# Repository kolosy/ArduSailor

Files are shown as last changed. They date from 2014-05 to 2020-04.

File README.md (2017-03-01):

ArduSailor
==========
ArduSailor is an autonomous sail boat project based on the Arduino platform. Using a modified Arduino Mega board (schematics under `layout`), ArduSailor can be programmed with a set of GPS waypoints that it can then sail to.

The platform is built around a simple, two-servo sail boat design, with a winch servo for sail plan control and a rudder servo for steering. The circuit layout included is for a modified Arduino Mega 2560, which includes:

* A 9DOF IMU (an Invensense MPU9250)
* A break-out for a weather vane (this circuit is also included)
* A microSD card
* Two servo breakouts
* Three power regulators (one to provide 6V for the servos, one to provide 3.3V for the rest and one MPPT solar charger for the LiPo)
* A GPS chip (Venus 638FPLx)
* A breakout for a UART-based camera module (currently unused)
* A battery input (currently running from a 3S LiPo battery pack)
* A breakout for the main UART port for logging (on my build I have this routed to a 433MHz radio module)
* ICSP header for programming

The included firmware operates off of a list of GPS waypoints, and is a very rudimentary implementation of a greedy algorithm for navigation. The pilot simply tries to point the boat as close to the next waypoint as it can, without falling into irons. Tacks are limited by a timer. A recent addition is stall control - if boat speed falls below a certain limit, it will fall off to beam reach (position itself with the wind coming in at a 90 degree angle) until it comes back up to speed. There is no cross-track correction

Status
======
I've built several iterations of the circuit board, and it works reliably. When at speed, the navigation works .. somewhat. My current testing is in a sub-optimal body of water (a long, narrow channel), making certain tests difficult.

Here's what I need to tackle

Short-term
----------
* Finish debugging basic piloting and navigation.
* Add cross-track correction
* Add heel compensation
* Add camera module support

Longer-term
-----------
* Improve the navigation algorithm to include no-go zones
* Add wind speed sensor (hw)

Pie-in-the-sky
--------
I'd like to replace the pilot code entirely with AI. This should be reduce-able to an optimization problem... but that's a bit beyond me right now.

Enjoy!

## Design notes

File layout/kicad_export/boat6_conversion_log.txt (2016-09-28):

#********** START OF renumber-sheet.ulp ULP Version 4.4.4 05-09-2016 :21:45:09 LOG **********#
#OldRef				SheetNumber	NewRef
CAM				1	CAM45
STATUS				1	STATUS45
S_RUD				1	S_RUD45
S_WINCH				1	S_WINCH45
WIND				1	WIND45
#********** END OF renumber-sheet.ulp ULP Version 4.4.4 05-09-2016 :21:45:09 LOG **********#

#********** START OF fix_via_hack.ulp ULP Version 4.6.0 05-09-2016 :21:45:46 LOG **********#
TRACK	WireCount=1		Net=GND				start(X=75950.000000 Y=27750.000000)	end(X=77000.000000 Y=27750.000000 )
TRACK	WireCount=2		Net=GND				start(X=77000.000000 Y=27750.000000)	end(X=77000.000000 Y=27850.000000 )
TRACK	WireCount=3		Net=GND				start(X=60000.000000 Y=12000.000000)	end(X=60000.000000 Y=11000.000000 )
TRACK	WireCount=4		Net=GND				start(X=23850.000000 Y=46100.000000)	end(X=23850.000000 Y=45300.000000 )
TRACK	WireCount=5		Net=GND				start(X=23850.000000 Y=45300.000000)	end(X=24250.000000 Y=45300.000000 )
TRACK	WireCount=6		Net=GND				start(X=24250.000000 Y=45300.000000)	end(X=24250.000000 Y=45700.000000 )
TRACK	WireCount=7		Net=GND				start(X=24250.000000 Y=45700.000000)	end(X=24100.000000 Y=45700.000000 )
TRACK	WireCount=8		Net=GND				start(X=76000.000000 Y=27750.000000)	end(X=75850.000000 Y=27750.000000 )
TRACK	WireCount=9		Net=GND				start(X=75600.000000 Y=28000.000000)	end(X=75550.000000 Y=28000.000000 )
TRACK	WireCount=10		Net=GND				start(X=75550.000000 Y=28000.000000)	end(X=75550.000000 Y=29600.000000 )
TRACK	WireCount=11		Net=GND				start(X=75550.000000 Y=29600.000000)	end(X=76450.000000 Y=29600.000000 )
TRACK	WireCount=12		Net=GND				start(X=76450.000000 Y=29600.000000)	end(X=76450.000000 Y=29500.000000 )
TRACK	WireCount=13		Net=GND				start(X=76450.000000 Y=29500.000000)	end(X=76350.000000 Y=29500.000000 )
TRACK	WireCount=14		Net=GND				start(X=76350.000000 Y=29500.000000)	end(X=76350.000000 Y=28200.000000 )
TRACK	WireCount=15		Net=GND				start(X=76350.000000 Y=28200.000000)	end(X=75900.000000 Y=28200.000000 )
TRACK	WireCount=16		Net=GND				start(X=75900.000000 Y=28200.000000)	end(X=75900.000000 Y=29100.000000 )
VIA	ViaCount=1		Net=3.3V				(X=70000.000000 Y=36000.000000)	LayerStart=1	LayerEnd=16
VIA	ViaCount=2		Net=GND				(X=17970.000000 Y=10285.000000)	LayerStart=1	LayerEnd=16
VIA	ViaCount=3		Net=GND				(X=16970.000000 Y=17317.500000)	LayerStart=1	LayerEnd=16
VIA	ViaCount=4		Net=GND				(X=22270.000000 Y=8390.000000)	LayerStart=1	LayerEnd=16
VIA	ViaCount=5		Net=GND				(X=63000.000000 Y=22000.000000)	LayerStart=1	LayerEnd=16
VIA	ViaCount=6		Net=GND				(X=78000.000000 Y=8000.000000)	LayerStart=1	LayerEnd=16
VIA	ViaCount=7		Net=GND				(X=76000.000000 Y=24000.000000)	LayerStart=1	LayerEnd=16
VIA	ViaCount=8		Net=GND				(X=76000.000000 Y=22000.000000)	LayerStart=1	LayerEnd=16
VIA	ViaCount=9		Net=GND				(X=75000.000000 Y=22000.000000)	LayerStart=1	LayerEnd=16
VIA	ViaCount=10		Net=GND				(X=75450.000000 Y=34400.000000)	LayerStart=1	LayerEnd=16
VIA	ViaCount=11		Net=GND				(X=41000.000000 Y=11000.000000)	LayerStart=1	LayerEnd=16
VIA	ViaCount=12		Net=GND				(X=53000.000000 Y=41000.000000)	LayerStart=1	LayerEnd=16
VIA	ViaCount=13		Net=GND				(X=32000.000000 Y=39000.000000)	LayerStart=1	LayerEnd=16
VIA	ViaCount=14		Net=GND				(X=4000.000000 Y=26000.000000)	LayerStart=1	LayerEnd=16
VIA	ViaCount=15		Net=GND				(X=10000.000000 Y=21000.000000)	LayerStart=1	LayerEnd=16
VIA	ViaCount=16		Net=GND				(X=4000.000000 Y=21000.000000)	LayerStart=1	LayerEnd=16
VIA	ViaCount=17		Net=GND				(X=34000.000000 Y=6000.000000)	LayerStart=1	LayerEnd=16
VIA	ViaCount=18		Net=GND				(X=40000.000000 Y=27000.000000)	LayerStart=1	LayerEnd=16
VIA	ViaCount=19		Net=GND				(X=30200.000000 Y=30150.000000)	LayerStart=1	LayerEnd=16
VIA	ViaCount=20		Net=GND				(X=10000.000000 Y=26000.000000)	LayerStart=1	LayerEnd=16
VIA	ViaCount=21		Net=GND				(X=3850.000000 Y=33350.000000)	LayerStart=1	LayerEnd=16
VIA	ViaCount=22		Net=GND				(X=14000.000000 Y=29000.000000)	LayerStart=1	LayerEnd=16
VIA	ViaCount=23		Net=GND				(X=33450.000000 Y=20700.000000)	LayerStart=1	LayerEnd=16
VIA	ViaCount=24		Net=GND				(X=65000.000000 Y=41000.000000)	LayerStart=1	LayerEnd=16
VIA	ViaCount=25		Net=GND				(X=63000.000000 Y=27000.000000)	LayerStart=1	LayerEnd=16
VIA	ViaCount=26		Net=GND				(X=57000.000000 Y=35000.000000)	LayerStart=1	LayerEnd=16
VIA	ViaCount=27		Net=GND				(X=63000.000000 Y=17000.000000)	LayerStart=1	LayerEnd=16
VIA	ViaCount=28		Net=GND				(X=76000.000000 Y=33400.000000)	LayerStart=1	LayerEnd=16
VIA	ViaCount=29		Net=GND				(X=73000.000000 Y=45000.000000)	LayerStart=1	LayerEnd=16
VIA	ViaCount=30		Net=GND				(X=63000.000000 Y=32000.000000)	LayerStart=1	LayerEnd=16
VIA	ViaCount=31		Net=GND				(X=42000.000000 Y=52000.000000)	LayerStart=1	LayerEnd=16
VIA	ViaCount=32		Net=GND				(X=29000.000000 Y=17000.000000)	LayerStart=1	LayerEnd=16
VIA	ViaCount=33		Net=GND				(X=79000.000000 Y=45000.000000)	LayerStart=1	LayerEnd=16
VIA	ViaCount=34		Net=GND				(X=41000.000000 Y=16000.000000)	LayerStart=1	LayerEnd=16
VIA	ViaCount=35		Net=GND				(X=75000.000000 Y=24000.000000)	LayerStart=1	LayerEnd=16
VIA	ViaCount=36		Net=GND				(X=81000.000000 Y=9000.000000)	LayerStart=1	LayerEnd=16
VIA	ViaCount=37		Net=GND				(X=82000.000000 Y=11000.000000)	LayerStart=1	LayerEnd=16
VIA	ViaCount=38		Net=GND				(X=76550.000000 Y=34400.000000)	LayerStart=1	LayerEnd=16
VIA	ViaCount=39		Net=GND				(X=63000.000000 Y=2000.000000)	LayerStart=1	LayerEnd=16
VIA	ViaCount=40		Net=GND				(X=58000.000000 Y=2000.000000)	LayerStart=1	LayerEnd=16
VIA	ViaCount=41		Net=GND				(X=57650.000000 Y=40550.000000)	LayerStart=1	LayerEnd=16
VIA	ViaCount=42		Net=GND				(X=53000.000000 Y=2000.000000)	LayerStart=1	LayerEnd=16
VIA	ViaCount=43		Net=GND				(X=53000.000000 Y=6000.000000)	LayerStart=1	LayerEnd=16
VIA	ViaCount=44		Net=GND				(X=35000.000000 Y=41000.000000)	LayerStart=1	LayerEnd=16
VIA	ViaCount=45		Net=GND				(X=65000.000000 Y=45000.000000)	LayerStart=1	LayerEnd=16
VIA	ViaCount=46		Net=GND				(X=73000.000000 Y=50000.000000)	LayerStart=1	LayerEnd=16
VIA	ViaCount=47		Net=GND				(X=15000.000000 Y=21000.000000)	LayerStart=1	LayerEnd=16
VIA	ViaCount=48		Net=GND				(X=25000.000000 Y=30000.000000)	LayerStart=1	LayerEnd=16
VIA	ViaCount=49		Net=GND				(X=27150.000000 Y=30000.000000)	LayerStart=1	LayerEnd=16
VIA	ViaCount=50		Net=GND				(X=24886.000000 Y=46563.000000)	LayerStart=1	LayerEnd=16
VIA	ViaCount=51		Net=GND				(X=25836.000000 Y=46763.000000)	LayerStart=1	LayerEnd=16
VIA	ViaCount=52		Net=GND				(X=43000.000000 Y=20000.000000)	LayerStart=1	LayerEnd=16
VIA	ViaCount=53		Net=GND				(X=49000.000000 Y=12000.000000)	LayerStart=1	LayerEnd=16
VIA	ViaCount=54		Net=GND				(X=79000.000000 Y=8000.000000)	LayerStart=1	LayerEnd=16
VIA	ViaCount=55		Net=GND				(X=81000.000000 Y=8000.000000)	LayerStart=1	LayerEnd=16
VIA	ViaCount=56		Net=GND				(X=19000.000000 Y=21000.000000)	LayerStart=1	LayerEnd=16
VIA	ViaCount=57		Net=GND				(X=49000.000000 Y=19900.000000)	LayerStart=1	LayerEnd=16
VIA	ViaCount=58		Net=GND				(X=10000.000000 Y=35000.000000)	LayerStart=1	LayerEnd=16
VIA	ViaCount=59		Net=GND				(X=13000.000000 Y=4000.000000)	LayerStart=1	LayerEnd=16
VIA	ViaCount=60		Net=GND				(X=29200.000000 Y=36150.000000)	LayerStart=1	LayerEnd=16
VIA	ViaCount=61		Net=GND				(X=69000.000000 Y=41000.000000)	LayerStart=1	LayerEnd=16
VIA	ViaCount=62		Net=GND				(X=43000.000000 Y=9000.000000)	LayerStart=1	LayerEnd=16
VIA	ViaCount=63		Net=GND				(X=48000.000000 Y=9000.000000)	LayerStart=1	LayerEnd=16
VIA	ViaCount=64		Net=GND				(X=52500.000000 Y=27800.000000)	LayerStart=1	LayerEnd=16
VIA	ViaCount=65		Net=GND				(X=81000.000000 Y=10000.000000)	LayerStart=1	LayerEnd=16
VIA	ViaCount=66		Net=GND				(X=45900.000000 Y=32250.000000)	LayerStart=1	LayerEnd=16
VIA	ViaCount=67		Net=GND				(X=77000.000000 Y=8000.000000)	LayerStart=1	LayerEnd=16
VIA	ViaCount=68		Net=GND				(X=76000.000000 Y=8000.000000)	LayerStart=1	LayerEnd=16
VIA	ViaCount=69		Net=GND				(X=76000.000000 Y=25000.000000)	LayerStart=1	LayerEnd=16
VIA	ViaCount=70		Net=GND				(X=40100.000000 Y=36400.000000)	LayerStart=1	LayerEnd=16
VIA	ViaCount=71		Net=GND				(X=63000.000000 Y=12000.000000)	LayerStart=1	LayerEnd=16
VIA	ViaCount=72		Net=GND				(X=63000.000000 Y=6000.000000)	LayerStart=1	LayerEnd=16
VIA	ViaCount=73		Net=GND				(X=19000.000000 Y=45000.000000)	LayerStart=1	LayerEnd=16
VIA	ViaCount=74		Net=GND				(X=19000.000000 Y=50000.000000)	LayerStart=1	LayerEnd=16
VIA	ViaCount=75		Net=GND				(X=34000.000000 Y=14000.000000)	LayerStart=1	LayerEnd=16
VIA	ViaCount=76		Net=GND				(X=34000.000000 Y=3000.000000)	LayerStart=1	LayerEnd=16
VIA	ViaCount=77		Net=GND				(X=44500.000000 Y=36400.000000)	LayerStart=1	LayerEnd=16
VIA	ViaCount=78		Net=GND				(X=43800.000000 Y=39800.000000)	LayerStart=1	LayerEnd=16
VIA	ViaCount=79		Net=GND				(X=44600.000000 Y=39800.000000)	LayerStart=1	LayerEnd=16
VIA	ViaCount=80		Net=GND				(X=29000.000000 Y=45000.000000)	LayerStart=1	LayerEnd=16
VIA	ViaCount=81		Net=GND				(X=35000.000000 Y=45000.000000)	LayerStart=1	LayerEnd=16
VIA	ViaCount=82		Net=GND				(X=76550.000000 Y=36400.000000)	LayerStart=1	LayerEnd=16
VIA	ViaCount=83		Net=GND				(X=75450.000000 Y=36400.000000)	LayerStart=1	LayerEnd=16
VIA	ViaCount=84		Net=GND				(X=47300.000000 Y=41950.000000)	LayerStart=1	LayerEnd=16
VIA	ViaCount=85		Net=GND				(X=40200.000000 Y=16000.000000)	LayerStart=1	LayerEnd=16
VIA	ViaCount=86		Net=GND				(X=41800.000000 Y=16000.000000)	LayerStart=1	LayerEnd=16
VIA	ViaCount=87		Net=GND				(X=84900.000000 Y=39800.000000)	LayerStart=1	LayerEnd=16
VIA	ViaCount=88		Net=GND				(X=85800.000000 Y=41850.000000)	LayerStart=1	LayerEnd=16
VIA	ViaCount=89		Net=GND				(X=32000.000000 Y=38000.000000)	LayerStart=1	LayerEnd=16
VIA	ViaCount=90		Net=GND				(X=29550.000000 Y=30750.000000)	LayerStart=1	LayerEnd=16
VIA	ViaCount=91		Net=GND				(X=38250.000000 Y=17550.000000)	LayerStart=1	LayerEnd=16
VIA	ViaCount=92		Net=GND				(X=37400.000000 Y=17550.000000)	LayerStart=1	LayerEnd=16
VIA	ViaCount=93		Net=GND				(X=54250.000000 Y=28950.000000)	LayerStart=1	LayerEnd=16
VIA	ViaCount=94		Net=GND				(X=54250.000000 Y=29750.000000)	LayerStart=1	LayerEnd=16
VIA	ViaCount=95		Net=GND				(X=48350.000000 Y=29800.000000)	LayerStart=1	LayerEnd=16
VIA	ViaCount=96		Net=GND				(X=45600.000000 Y=28250.000000)	LayerStart=1	LayerEnd=16
VIA	ViaCount=97		Net=RFGND				(X=4000.000000 Y=3300.000000)	LayerStart=1	LayerEnd=16
VIA	ViaCount=98		Net=RFGND				(X=1460.000000 Y=18540.000000)	LayerStart=1	LayerEnd=16
VIA	ViaCount=99		Net=RFGND				(X=1460.000000 Y=3300.000000)	LayerStart=1	LayerEnd=16
VIA	ViaCount=100		Net=RFGND				(X=1460.000000 Y=12190.000000)	LayerStart=1	LayerEnd=16
VIA	ViaCount=101		Net=RFGND				(X=4000.000000 Y=12190.000000)	LayerStart=1	LayerEnd=16
PADFILL	PadCount=1		Net=3.3V				(X=54200.000000 Y=10280.000000)	LayerStart=1	LayerEnd=1
PADFILL	PadCount=2		Net=GND				(X=54200.000000 Y=11980.000000)	LayerStart=1	LayerEnd=1
PADFILL	PadCount=4		Net=GND				(X=58100.000000 Y=15070.000000)	LayerStart=1	LayerEnd=1
PADFILL	PadCount=5		Net=3.3V				(X=60780.000000 Y=8470.000000)	LayerStart=1	LayerEnd=1
PADFILL	PadCount=6		Net=GND				(X=62480.000000 Y=8470.000000)	LayerStart=1	LayerEnd=1
PADFILL	PadCount=8		Net=GND				(X=57910.000000 Y=4570.000000)	LayerStart=1	LayerEnd=1
PADFILL	PadCount=10		Net=GND				(X=21930.000000 Y=11770.000000)	LayerStart=1	LayerEnd=1
PADFILL	PadCount=12		Net=GND				(X=19875.000000 Y=12320.000000)	LayerStart=1	LayerEnd=1
PADFILL	PadCount=14		Net=GND				(X=20492.500000 Y=7007.500000)	LayerStart=1	LayerEnd=1
PADFILL	PadCount=16		Net=RFGND				(X=7479.000000 Y=4735.000000)	LayerStart=1	LayerEnd=1
PADFILL	PadCount=20		Net=GND				(X=19025.000000 Y=16476.100000)	LayerStart=1	LayerEnd=1
PADFILL	PadCount=22		Net=GND				(X=36900.000000 Y=41289.000000)	LayerStart=1	LayerEnd=1
PADFILL	PadCount=23		Net=3.3V				(X=51511.000000 Y=29350.000000)	LayerStart=1	LayerEnd=1
PADFILL	PadCount=24		Net=GND				(X=53289.000000 Y=29350.000000)	LayerStart=1	LayerEnd=1
PADFILL	PadCount=27		Net=3.3V				(X=32539.000000 Y=31850.000000)	LayerStart=1	LayerEnd=1
PADFILL	PadCount=28		Net=GND				(X=30761.000000 Y=31850.000000)	LayerStart=1	LayerEnd=1
PADFILL	PadCount=29		Net=3.3V				(X=35089.000000 Y=38250.000000)	LayerStart=1	LayerEnd=1
PADFILL	PadCount=30		Net=GND				(X=33311.000000 Y=38250.000000)	LayerStart=1	LayerEnd=1
PADFILL	PadCount=32		Net=GND				(X=37750.000000 Y=18711.000000)	LayerStart=1	LayerEnd=1
PADFILL	PadCount=33		Net=V_BATT				(X=85400.000000 Y=8850.000000)	LayerStart=1	LayerEnd=1
PADFILL	PadCount=34		Net=GND				(X=82600.000000 Y=8850.000000)	LayerStart=1	LayerEnd=1
PADFILL	PadCount=35		Net=5V				(X=83100.000000 Y=21050.000000)	LayerStart=1	LayerEnd=1
PADFILL	PadCount=39		Net=5V				(X=76000.000000 Y=3600.000000)	LayerStart=1	LayerEnd=1
PADFILL	PadCount=40		Net=GND				(X=76000.000000 Y=6400.000000)	LayerStart=1	LayerEnd=1
PADFILL	PadCount=41		Net=V_BATT				(X=77900.000000 Y=26700.000000)	LayerStart=1	LayerEnd=1
PADFILL	PadCount=42		Net=GND				(X=76100.000000 Y=26700.000000)	LayerStart=1	LayerEnd=1
PADFILL	PadCount=43		Net=3.3V				(X=74100.000000 Y=31450.000000)	LayerStart=1	LayerEnd=1
PADFILL	PadCount=44		Net=GND				(X=75900.000000 Y=31450.000000)	LayerStart=1	LayerEnd=1
PADFILL	PadCount=45		Net=GND				(X=26350.000000 Y=27900.000000)	LayerStart=1	LayerEnd=1
PADFILL	PadCount=46		Net=3.3V				(X=26350.000000 Y=38100.000000)	LayerStart=1	LayerEnd=1
PADFILL	PadCount=49		Net=3.3V				(X=23840.000000 Y=41010.000000)	LayerStart=1	LayerEnd=1
PADFILL	PadCount=50		Net=GND				(X=25540.000000 Y=41010.000000)	LayerStart=1	LayerEnd=1
PADFILL	PadCount=54		Net=GND				(X=25320.000000 Y=48191.000000)	LayerStart=1	LayerEnd=1
PADFILL	PadCount=55		Net=3.3V				(X=46100.000000 Y=39550.000000)	LayerStart=1	LayerEnd=1
PADFILL	PadCount=56		Net=GND				(X=46100.000000 Y=41250.000000)	LayerStart=1	LayerEnd=1
PADFILL	PadCount=59		Net=GND				(X=26700.000000 Y=4200.000000)	LayerStart=1	LayerEnd=1
PADFILL	PadCount=61		Net=5V				(X=78000.000000 Y=3600.000000)	LayerStart=1	LayerEnd=1
PADFILL	PadCount=62		Net=GND				(X=78000.000000 Y=6400.000000)	LayerStart=1	LayerEnd=1
PADFILL	PadCount=63		Net=V_BATT				(X=84900.000000 Y=10600.000000)	LayerStart=1	LayerEnd=1
PADFILL	PadCount=64		Net=GND				(X=83100.000000 Y=10600.000000)	LayerStart=1	LayerEnd=1
PADFILL	PadCount=65		Net=3.3V				(X=78500.000000 Y=33400.000000)	LayerStart=1	LayerEnd=1
PADFILL	PadCount=74		Net=5V				(X=50300.000000 Y=47000.000000)	LayerStart=1	LayerEnd=1
PADFILL	PadCount=76		Net=5V				(X=61950.000000 Y=47000.000000)	LayerStart=1	LayerEnd=1
PADFILL	PadCount=80		Net=3.3V				(X=46300.000000 Y=14000.000000)	LayerStart=1	LayerEnd=1
PADFILL	PadCount=90		Net=3.3V				(X=34000.000000 Y=31500.000000)	LayerStart=1	LayerEnd=1
PADFILL	PadCount=91		Net=GND				(X=34000.000000 Y=31000.000000)	LayerStart=1	LayerEnd=1
PADFILL	PadCount=111		Net=3.3V				(X=38500.000000 Y=22000.000000)	LayerStart=1	LayerEnd=1
PADFILL	PadCount=112		Net=GND				(X=39000.000000 Y=22000.000000)	LayerStart=1	LayerEnd=1
PADFILL	PadCount=141		Net=3.3V				(X=50000.000000 Y=29000.000000)	LayerStart=1	LayerEnd=1
PADFILL	PadCount=142		Net=GND				(X=50000.000000 Y=29500.000000)	LayerStart=1	LayerEnd=1
PADFILL	PadCount=160		Net=3.3V				(X=46000.000000 Y=38000.000000)	LayerStart=1	LayerEnd=1
PADFILL	PadCount=161		Net=GND				(X=45500.000000 Y=38000.000000)	LayerStart=1	LayerEnd=1
PADFILL	PadCount=179		Net=GND				(X=36500.000000 Y=38000.000000)	LayerStart=1	LayerEnd=1
PADFILL	PadCount=180		Net=3.3V				(X=36000.000000 Y=38000.000000)	LayerStart=1	LayerEnd=1
PADFILL	PadCount=196		Net=RFGND				(X=2323.600000 Y=10259.600000)	LayerStart=1	LayerEnd=1
PADFILL	PadCount=197		Net=RFGND				(X=2323.600000 Y=5179.600000)	LayerStart=1	LayerEnd=1
PADFILL	PadCount=198		Net=RFGND				(X=2323.600000 Y=10259.600000)	LayerStart=16	LayerEnd=16
PADFILL	PadCount=199		Net=RFGND				(X=2323.600000 Y=5179.600000)	LayerStart=16	LayerEnd=16
PADFILL	PadCount=204		Net=3.3V				(X=71950.000000 Y=29370.000000)	LayerStart=1	LayerEnd=1
PADFILL	PadCount=206		Net=5V				(X=80000.000000 Y=4150.000000)	LayerStart=1	LayerEnd=1
PADFILL	PadCount=208		Net=GND				(X=85050.000000 Y=41100.000000)	LayerStart=1	LayerEnd=1
PADFILL	PadCount=211		Net=3.3V				(X=6050.000000 Y=46000.000000)	LayerStart=1	LayerEnd=1
PADFILL	PadCount=214		Net=3.3V				(X=33000.000000 Y=11950.000000)	LayerStart=1	LayerEnd=1
PADFILL	PadCount=217		Net=3.3V				(X=17250.000000 Y=39100.000000)	LayerStart=1	LayerEnd=1
PADFILL	PadCount=220		Net=GND				(X=68100.000000 Y=48950.000000)	LayerStart=1	LayerEnd=1
PADFILL	PadCount=223		Net=GND				(X=57100.000000 Y=48950.000000)	LayerStart=1	LayerEnd=1
PADFILL	PadCount=226		Net=GND				(X=82950.000000 Y=40900.000000)	LayerStart=1	LayerEnd=1
PADFILL	PadCount=229		Net=V_BATT				(X=82950.000000 Y=45050.000000)	LayerStart=1	LayerEnd=1
PADFILL	PadCount=231		Net=V_BATT				(X=80000.000000 Y=26150.000000)	LayerStart=1	LayerEnd=1
PADFILL	PadCount=233		Net=3.3V				(X=6150.000000 Y=48000.000000)	LayerStart=1	LayerEnd=1
PADFILL	PadCount=237		Net=GND				(X=20725.000000 Y=15215.000000)	LayerStart=1	LayerEnd=1
PADFILL	PadCount=243		Net=GND				(X=8762.500000 Y=7720.000000)	LayerStart=16	LayerEnd=16
PADFILL	PadCount=244		Net=RFGND				(X=7492.500000 Y=7720.000000)	LayerStart=16	LayerEnd=16
PADFILL	PadCount=251		Net=GND				(X=85150.000000 Y=48300.000000)	LayerStart=1	LayerEnd=1
PADFILL	PadCount=258		Net=5V				(X=83150.000000 Y=19500.000000)	LayerStart=1	LayerEnd=1
PADFILL	PadCount=259		Net=GND				(X=83150.000000 Y=18000.000000)	LayerStart=1	LayerEnd=1
PADFILL	PadCount=262		Net=3.3V				(X=78650.000000 Y=31900.000000)	LayerStart=1	LayerEnd=1
PADFILL	PadCount=263		Net=GND				(X=80700.000000 Y=31900.000000)	LayerStart=1	LayerEnd=1
PADFILL	PadCount=265		Net=3.3V				(X=71150.000000 Y=24000.000000)	LayerStart=1	LayerEnd=1
PADFILL	PadCount=267		Net=V_BATT				(X=86850.000000 Y=45000.000000)	LayerStart=1	LayerEnd=1
PADFILL	PadCount=269		Net=3.3V				(X=8900.000000 Y=41450.000000)	LayerStart=1	LayerEnd=1
PADFILL	PadCount=271		Net=3.3V				(X=35000.000000 Y=11850.000000)	LayerStart=1	LayerEnd=1
PADFILL	PadCount=280		Net=GND				(X=53050.000000 Y=21200.000000)	LayerStart=1	LayerEnd=1
PADFILL	PadCount=283		Net=GND				(X=82850.000000 Y=39000.000000)	LayerStart=1	LayerEnd=1
PADFILL	PadCount=290		Net=3.3V				(X=43325.000000 Y=17400.000000)	LayerStart=1	LayerEnd=1
PADFILL	PadCount=291		Net=3.3V				(X=43325.000000 Y=16600.000000)	LayerStart=1	LayerEnd=1
PADFILL	PadCount=292		Net=3.3V				(X=43325.000000 Y=15800.000000)	LayerStart=1	LayerEnd=1
PADFILL	PadCount=301		Net=GND				(X=77060.000000 Y=28250.000000)	LayerStart=1	LayerEnd=1
PADFILL	PadCount=302		Net=V_BATT				(X=77060.000000 Y=28750.000000)	LayerStart=1	LayerEnd=1
PADFILL	PadCount=306		Net=3.3V				(X=74950.000000 Y=29250.000000)	LayerStart=1	LayerEnd=1
PADFILL	PadCount=309		Net=GND				(X=76000.000000 Y=29000.000000)	LayerStart=1	LayerEnd=1
PADFILL	PadCount=312		Net=GND				(X=83050.000000 Y=12850.000000)	LayerStart=1	LayerEnd=1
PADFILL	PadCount=314		Net=V_BATT				(X=84950.000000 Y=12850.000000)	LayerStart=1	LayerEnd=1
PADFILL	PadCount=318		Net=GND				(X=55510.000000 Y=11270.000000)	LayerStart=1	LayerEnd=1
PADFILL	PadCount=320		Net=3.3V				(X=55510.000000 Y=10270.000000)	LayerStart=1	LayerEnd=1
PADFILL	PadCount=325		Net=3.3V				(X=56760.000000 Y=8020.000000)	LayerStart=1	LayerEnd=1
PADFILL	PadCount=326		Net=GND				(X=57260.000000 Y=8020.000000)	LayerStart=1	LayerEnd=1
PADFILL	PadCount=328		Net=GND				(X=58260.000000 Y=8020.000000)	LayerStart=1	LayerEnd=1
PADFILL	PadCount=330		Net=3.3V				(X=59510.000000 Y=8770.000000)	LayerStart=1	LayerEnd=1
PADFILL	PadCount=332		Net=GND				(X=59510.000000 Y=9770.000000)	LayerStart=1	LayerEnd=1
PADFILL	PadCount=334		Net=GND				(X=59510.000000 Y=10770.000000)	LayerStart=1	LayerEnd=1
PADFILL	PadCount=335		Net=GND				(X=59510.000000 Y=11270.000000)	LayerStart=1	LayerEnd=1
PADFILL	PadCount=349		Net=GND				(X=16520.000000 Y=12520.000000)	LayerStart=1	LayerEnd=1
PADFILL	PadCount=351		Net=GND				(X=16520.000000 Y=14120.000000)	LayerStart=1	LayerEnd=1
PADFILL	PadCount=352		Net=GND				(X=16520.000000 Y=14920.000000)	LayerStart=1	LayerEnd=1
PADFILL	PadCount=356		Net=GND				(X=13220.000000 Y=15820.000000)	LayerStart=1	LayerEnd=1
PADFILL	PadCount=360		Net=GND				(X=10020.000000 Y=15820.000000)	LayerStart=1	LayerEnd=1
PADFILL	PadCount=362		Net=RFGND				(X=8420.000000 Y=15820.000000)	LayerStart=1	LayerEnd=1
PADFILL	PadCount=363		Net=RFGND				(X=7620.000000 Y=15820.000000)	LayerStart=1	LayerEnd=1
PADFILL	PadCount=365		Net=RFGND				(X=6720.000000 Y=14120.000000)	LayerStart=1	LayerEnd=1
PADFILL	PadCount=366		Net=RFGND				(X=6720.000000 Y=13320.000000)	LayerStart=1	LayerEnd=1
PADFILL	PadCount=368		Net=RFGND				(X=6720.000000 Y=11720.000000)	LayerStart=1	LayerEnd=1
PADFILL	PadCount=369		Net=RFGND				(X=6720.000000 Y=10920.000000)	LayerStart=1	LayerEnd=1
PADFILL	PadCount=370		Net=RFGND				(X=6720.000000 Y=10120.000000)	LayerStart=1	LayerEnd=1
PADFILL	PadCount=372		Net=RFGND				(X=6720.000000 Y=8520.000000)	LayerStart=1	LayerEnd=1
PADFILL	PadCount=374		Net=RFGND				(X=6720.000000 Y=6920.000000)	LayerStart=1	LayerEnd=1
PADFILL	PadCount=390		Net=GND				(X=14620.000000 Y=13920.000000)	LayerStart=1	LayerEnd=1
PADFILL	PadCount=401		Net=GND				(X=10120.000000 Y=7920.000000)	LayerStart=1	LayerEnd=1
PADFILL	PadCount=402		Net=RFGND				(X=10120.000000 Y=9420.000000)	LayerStart=1	LayerEnd=1
PADFILL	PadCount=403		Net=RFGND				(X=10120.000000 Y=10920.000000)	LayerStart=1	LayerEnd=1
PADFILL	PadCount=405		Net=GND				(X=10120.000000 Y=13920.000000)	LayerStart=1	LayerEnd=1
PADFILL	PadCount=406		Net=RFGND				(X=8620.000000 Y=7920.000000)	LayerStart=1	LayerEnd=1
PADFILL	PadCount=410		Net=RFGND				(X=8620.000000 Y=13920.000000)	LayerStart=1	LayerEnd=1
PADFILL	PadCount=414		Net=3.3V				(X=5230.000000 Y=31870.000000)	LayerStart=1	LayerEnd=1
PADFILL	PadCount=416		Net=GND				(X=5230.000000 Y=34070.000000)	LayerStart=1	LayerEnd=1
PADFILL	PadCount=419		Net=GND				(X=15730.000000 Y=35460.000000)	LayerStart=1	LayerEnd=1
PADFILL	PadCount=420		Net=GND				(X=15730.000000 Y=29760.000000)	LayerStart=1	LayerEnd=1
PADFILL	PadCount=421		Net=GND				(X=1580.000000 Y=23910.000000)	LayerStart=1	LayerEnd=1
PADFILL	PadCount=422		Net=GND				(X=2580.000000 Y=37060.000000)	LayerStart=1	LayerEnd=1
PADFILL	PadCount=424		Net=3.3V				(X=22750.000000 Y=42630.000000)	LayerStart=1	LayerEnd=1
PADFILL	PadCount=426		Net=3.3V				(X=23750.000000 Y=42630.000000)	LayerStart=1	LayerEnd=1
PADFILL	PadCount=431		Net=GND				(X=23750.000000 Y=45370.000000)	LayerStart=1	LayerEnd=1
PADFILL	PadCount=433		Net=GND				(X=22750.000000 Y=45370.000000)	LayerStart=1	LayerEnd=1
PADFILL	PadCount=435		Net=3.3V				(X=21630.000000 Y=44750.000000)	LayerStart=1	LayerEnd=1
PADFILL	PadCount=444		Net=GND				(X=40800.000000 Y=17700.000000)	LayerStart=1	LayerEnd=1
#********** END OF fix_via_hack.ulp ULP Version 4.6.0 05-09-2016 :21:45:46 LOG **********#

#********** START OF eagle6xx-sch-to-kicad-sch.ulp 1.9 05-09-2016 :21:46:51 LOG **********#
Package Name Conflict: Package=C0402 from Internal SCH lib=SmartPrj  With Package=C0402 from LIB=SparkFun
Package Name Conflict: Package=R2010 from Internal SCH lib=SmartPrj  With Package=R2010 from LIB=SparkFun
Package Name Conflict: Package=R2010 from Internal SCH lib=SmartPrj  With Package=R2010 from LIB=SparkFun-Passives
Package Name Conflict: Package=R2010 from Internal SCH lib=SmartPrj  With Package=R2010 from LIB=SparkFun-Resistors
Package Name Conflict: Package=R2512 from Internal SCH lib=SmartPrj  With Package=R2512 from LIB=SparkFun
Package Name Conflict: Package=R2512 from Internal SCH lib=SmartPrj  With Package=R2512 from LIB=SparkFun-Passives
Package Name Conflict: Package=R2512 from Internal SCH lib=SmartPrj  With Package=R2512 from LIB=SparkFun-Resistors
Device Name Conflict: Device=CAP0402-CAP from Internal SCH lib=SparkFun  With Device=CAP0402-CAP from LIB=SparkFun-Capacitors
Device Name Conflict: Device=CAP0402-CAP from Internal SCH lib=SparkFun  With Device=CAP0402-CAP from LIB=SparkFun-Passives
Device Name Conflict: Device=CAP0603-CAP from Internal SCH lib=SparkFun  With Device=CAP0603-CAP from LIB=SparkFun-Capacitors
Device Name Conflict: Device=CAP0603-CAP from Internal SCH lib=SparkFun  With Device=CAP0603-CAP from LIB=SparkFun-Passives
Device Name Conflict: Device=CAP0805 from Internal SCH lib=SparkFun  With Device=CAP0805 from LIB=SparkFun-Capacitors
Device Name Conflict: Device=CAP0805 from Internal SCH lib=SparkFun  With Device=CAP0805 from LIB=SparkFun-Passives
Device Name Conflict: Device=CAP1206 from Internal SCH lib=SparkFun  With Device=CAP1206 from LIB=SparkFun-Capacitors
Device Name Conflict: Device=CAP1206 from Internal SCH lib=SparkFun  With Device=CAP1206 from LIB=SparkFun-Passives
Device Name Conflict: Device=CAP1210 from Internal SCH lib=SparkFun  With Device=CAP1210 from LIB=SparkFun-Capacitors
Device Name Conflict: Device=CAP1210 from Internal SCH lib=SparkFun  With Device=CAP1210 from LIB=SparkFun-Passives
Device Name Conflict: Device=CAPASMD from Internal SCH lib=SparkFun  With Device=CAPASMD from LIB=SparkFun-Capacitors
Device Name Conflict: Device=CAPASMD from Internal SCH lib=SparkFun  With Device=CAPASMD from LIB=SparkFun-Passives
Device Name Conflict: Device=CAPPTH from Internal SCH lib=SparkFun  With Device=CAPPTH from LIB=SparkFun-Capacitors
Device Name Conflict: Device=CAPPTH from Internal SCH lib=SparkFun  With Device=CAPPTH from LIB=SparkFun-Passives
Device Name Conflict: Device=CAPPTH1 from Internal SCH lib=SparkFun  With Device=CAPPTH1 from LIB=SparkFun-Capacitors
Device Name Conflict: Device=CAPPTH1 from Internal SCH lib=SparkFun  With Device=CAPPTH1 from LIB=SparkFun-Passives
Device Name Conflict: Device=CAPPTH2 from Internal SCH lib=SparkFun  With Device=CAPPTH2 from LIB=SparkFun-Capacitors
Device Name Conflict: Device=CAPPTH2 from Internal SCH lib=SparkFun  With Device=CAPPTH2 from LIB=SparkFun-Passives
Device Name Conflict: Device=CAPPTH3 from Internal SCH lib=SparkFun  With Device=CAPPTH3 from LIB=SparkFun-Capacitors
Device Name Conflict: Device=CAPPTH3 from Internal SCH lib=SparkFun  With Device=CAPPTH3 from LIB=SparkFun-Passives
Device Name Conflict: Device=CAPSMD from Internal SCH lib=SparkFun  With Device=CAPSMD from LIB=SparkFun-Capacitors
Device Name Conflict: Device=CAPSMD from Internal SCH lib=SparkFun  With Device=CAPSMD from LIB=SparkFun-Passives
Device Name Conflict: Device=CAP_ from Internal SCH lib=SparkFun  With Device=CAP_ from LIB=SparkFun-Capacitors
Device Name Conflict: Device=CAP_ from Internal SCH lib=SparkFun  With Device=CAP_ from LIB=SparkFun-Passives
Device Name Conflict: Device=CAP_POL1206 from Internal SCH lib=SparkFun  With Device=CAP_POL1206 from LIB=kolosy
Device Name Conflict: Device=CAP_POL1206-KIT from Internal SCH lib=SparkFun  With Device=CAP_POL1206-KIT from LIB=kolosy
Device Name Conflict: Device=CAP_POL3528 from Internal SCH lib=SparkFun  With Device=CAP_POL3528 from LIB=kolosy
Device Name Conflict: Device=CAP_POL3528-KIT from Internal SCH lib=SparkFun  With Device=CAP_POL3528-KIT from LIB=kolosy
Device Name Conflict: Device=CAP_POL6032 from Internal SCH lib=SparkFun  With Device=CAP_POL6032 from LIB=kolosy
Device Name Conflict: Device=CAP_POL7343 from Internal SCH lib=SparkFun  With Device=CAP_POL7343 from LIB=kolosy
Device Name Conflict: Device=CAP_POLC from Internal SCH lib=SparkFun  With Device=CAP_POLC from LIB=kolosy
Device Name Conflict: Device=CAP_POLD from Internal SCH lib=SparkFun  With Device=CAP_POLD from LIB=kolosy
Device Name Conflict: Device=CAP_POLE from Internal SCH lib=SparkFun  With Device=CAP_POLE from LIB=kolosy
Device Name Conflict: Device=CAP_POLEN_J2 from Internal SCH lib=SparkFun  With Device=CAP_POLEN_J2 from LIB=kolosy
Device Name Conflict: Device=CAP_POLF80 from Internal SCH lib=SparkFun  With Device=CAP_POLF80 from LIB=kolosy
Device Name Conflict: Device=CAP_POLG from Internal SCH lib=SparkFun  With Device=CAP_POLG from LIB=kolosy
Device Name Conflict: Device=CAP_POLH13 from Internal SCH lib=SparkFun  With Device=CAP_POLH13 from LIB=kolosy
Device Name Conflict: Device=CAP_POLPTH1 from Internal SCH lib=SparkFun  With Device=CAP_POLPTH1 from LIB=kolosy
Device Name Conflict: Device=CAP_POLPTH2 from Internal SCH lib=SparkFun  With Device=CAP_POLPTH2 from LIB=kolosy
Device Name Conflict: Device=CAP_POLPTH3 from Internal SCH lib=SparkFun  With Device=CAP_POLPTH3 from LIB=kolosy
Device Name Conflict: Device=CAP_POLPTH4 from Internal SCH lib=SparkFun  With Device=CAP_POLPTH4 from LIB=kolosy
Device Name Conflict: Device=CAP_POLSMD from Internal SCH lib=SparkFun  With Device=CAP_POLSMD from LIB=kolosy
Device Name Conflict: Device=GND from Internal SCH lib=SparkFun  With Device=GND from LIB=SparkFun-Aesthetics
Device Name Conflict: Device=GND from Internal SCH lib=SparkFun  With Device=GND from LIB=supply1
Device Name Conflict: Device=RESISTOR0402-RES from Internal SCH lib=SparkFun  With Device=RESISTOR0402-RES from LIB=SparkFun-Passives
Device Name Conflict: Device=RESISTOR0603-RES from Internal SCH lib=SparkFun  With Device=RESISTOR0603-RES from LIB=SparkFun-Passives
Device Name Conflict: Device=RESISTOR0603-RES from Internal SCH lib=SparkFun  With Device=RESISTOR0603-RES from LIB=SparkFun-Resistors
Device Name Conflict: Device=RESISTOR0805-RES from Internal SCH lib=SparkFun  With Device=RESISTOR0805-RES from LIB=SparkFun-Passives
Device Name Conflict: Device=RESISTOR0805-RES from Internal SCH lib=SparkFun  With Device=RESISTOR0805-RES from LIB=SparkFun-Resistors
Device Name Conflict: Device=RESISTOR1206 from Internal SCH lib=SparkFun  With Device=RESISTOR1206 from LIB=SparkFun-Passives
Device Name Conflict: Device=RESISTOR1206 from Internal SCH lib=SparkFun  With Device=RESISTOR1206 from LIB=SparkFun-Resistors
Device Name Conflict: Device=RESISTOR2010 from Internal SCH lib=SparkFun  With Device=RESISTOR2010 from LIB=SparkFun-Passives
Device Name Conflict: Device=RESISTOR2010 from Internal SCH lib=SparkFun  With Device=RESISTOR2010 from LIB=SparkFun-Resistors
Device Name Conflict: Device=RESISTOR2512 from Internal SCH lib=SparkFun  With Device=RESISTOR2512 from LIB=SparkFun-Passives
Device Name Conflict: Device=RESISTOR2512 from Internal SCH lib=SparkFun  With Device=RESISTOR2512 from LIB=SparkFun-Resistors
Device Name Conflict: Device=RESISTORAXIAL-0.3 from Internal SCH lib=SparkFun  With Device=RESISTORAXIAL-0.3 from LIB=SparkFun-Passives
Device Name Conflict: Device=RESISTORAXIAL-0.3 from Internal SCH lib=SparkFun  With Device=RESISTORAXIAL-0.3 from LIB=SparkFun-Resistors
Device Name Conflict: Device=RESISTORPTH-1/2W from Internal SCH lib=SparkFun  With Device=RESISTORPTH-1/2W from LIB=SparkFun-Passives
Device Name Conflict: Device=RESISTORPTH-1/2W from Internal SCH lib=SparkFun  With Device=RESISTORPTH-1/2W from LIB=SparkFun-Resistors
Device Name Conflict: Device=RESISTORPTH-1/4W from Internal SCH lib=SparkFun  With Device=RESISTORPTH-1/4W from LIB=SparkFun-Passives
Device Name Conflict: Device=RESISTORPTH-1/4W from Internal SCH lib=SparkFun  With Device=RESISTORPTH-1/4W from LIB=SparkFun-Resistors
Device Name Conflict: Device=RESISTORPTH-1/6W from Internal SCH lib=SparkFun  With Device=RESISTORPTH-1/6W from LIB=SparkFun-Passives
Device Name Conflict: Device=RESISTORPTH-1/6W from Internal SCH lib=SparkFun  With Device=RESISTORPTH-1/6W from LIB=SparkFun-Resistors
Device Name Conflict: Device=RESISTORPTH-1W from Internal SCH lib=SparkFun  With Device=RESISTORPTH-1W from LIB=SparkFun-Passives
Device Name Conflict: Device=RESISTORPTH-1W from Internal SCH lib=SparkFun  With Device=RESISTORPTH-1W from LIB=SparkFun-Resistors
Device Name Conflict: Device=RESISTORPTH-2W from Internal SCH lib=SparkFun  With Device=RESISTORPTH-2W from LIB=SparkFun-Passives
Device Name Conflict: Device=RESISTORPTH-2W from Internal SCH lib=SparkFun  With Device=RESISTORPTH-2W from LIB=SparkFun-Resistors
Symbol Name Conflict: Symbol=CAP from Internal SCH lib=SparkFun  With Symbol=CAP from LIB=SparkFun-Capacitors
Symbol Name Conflict: Symbol=CAP from Internal SCH lib=SparkFun  With Symbol=CAP from LIB=SparkFun-Passives
Symbol Name Conflict: Symbol=CAP_POL from Internal SCH lib=SparkFun  With Symbol=CAP_POL from LIB=kolosy
Symbol Name Conflict: Symbol=GND from Internal SCH lib=SparkFun  With Symbol=GND from LIB=supply1
Symbol Name Conflict: Symbol=RESISTOR from Internal SCH lib=SparkFun  With Symbol=RESISTOR from LIB=SparkFun-Passives
Symbol Name Conflict: Symbol=RESISTOR from Internal SCH lib=SparkFun  With Symbol=RESISTOR from LIB=SparkFun-Resistors
Package Name Conflict: Package=1/6W-RES from Internal SCH lib=SparkFun  With Package=1/6W-RES from LIB=SparkFun-Passives
Package Name Conflict: Package=1/6W-RES from Internal SCH lib=SparkFun  With Package=1/6W-RES from LIB=SparkFun-Resistors
Package Name Conflict: Package=0402-CAP from Internal SCH lib=SparkFun  With Package=0402-CAP from LIB=SparkFun-Capacitors
Package Name Conflict: Package=0402-CAP from Internal SCH lib=SparkFun  With Package=0402-CAP from LIB=SparkFun-Passives
Package Name Conflict: Package=0402-RES from Internal SCH lib=SparkFun  With Package=0402-RES from LIB=SparkFun-Passives
Package Name Conflict: Package=0603-CAP from Internal SCH lib=SparkFun  With Package=0603-CAP from LIB=SparkFun-Capacitors
Package Name Conflict: Package=0603-CAP from Internal SCH lib=SparkFun  With Package=0603-CAP from LIB=SparkFun-Passives
Package Name Conflict: Package=0603-RES from Internal SCH lib=SparkFun  With Package=0603-RES from LIB=SparkFun-Passives
Package Name Conflict: Package=0603-RES from Internal SCH lib=SparkFun  With Package=0603-RES from LIB=SparkFun-Resistors
Package Name Conflict: Package=0805 from Internal SCH lib=SparkFun  With Package=0805 from LIB=SparkFun-Capacitors
Package Name Conflict: Package=0805 from Internal SCH lib=SparkFun  With Package=0805 from LIB=SparkFun-Passives
Package Name Conflict: Package=0805 from Internal SCH lib=SparkFun  With Package=0805 from LIB=SparkFun-Resistors
Package Name Conflict: Package=1206 from Internal SCH lib=SparkFun  With Package=1206 from LIB=SparkFun-Capacitors
Package Name Conflict: Package=1206 from Internal SCH lib=SparkFun  With Package=1206 from LIB=SparkFun-Passives
Package Name Conflict: Package=1206 from Internal SCH lib=SparkFun  With Package=1206 from LIB=SparkFun-Resistors
Package Name Conflict: Package=1210 from Internal SCH lib=SparkFun  With Package=1210 from LIB=SparkFun-Capacitors
Package Name Conflict: Package=1210 from Internal SCH lib=SparkFun  With Package=1210 from LIB=SparkFun-Passives
Package Name Conflict: Package=AXIAL-0.3 from Internal SCH lib=SparkFun  With Package=AXIAL-0.3 from LIB=SparkFun-Passives
Package Name Conflict: Package=AXIAL-0.3 from Internal SCH lib=SparkFun  With Package=AXIAL-0.3 from LIB=SparkFun-Resistors
Package Name Conflict: Package=AXIAL-0.4 from Internal SCH lib=SparkFun  With Package=AXIAL-0.4 from LIB=SparkFun-Passives
Package Name Conflict: Package=AXIAL-0.4 from Internal SCH lib=SparkFun  With Package=AXIAL-0.4 from LIB=SparkFun-Resistors
Package Name Conflict: Package=AXIAL-0.5 from Internal SCH lib=SparkFun  With Package=AXIAL-0.5 from LIB=SparkFun-Passives
Package Name Conflict: Package=AXIAL-0.5 from Internal SCH lib=SparkFun  With Package=AXIAL-0.5 from LIB=SparkFun-Resistors
Package Name Conflict: Package=AXIAL-0.6 from Internal SCH lib=SparkFun  With Package=AXIAL-0.6 from LIB=SparkFun-Passives
Package Name Conflict: Package=AXIAL-0.6 from Internal SCH lib=SparkFun  With Package=AXIAL-0.6 from LIB=SparkFun-Resistors
Package Name Conflict: Package=AXIAL-0.8 from Internal SCH lib=SparkFun  With Package=AXIAL-0.8 from LIB=SparkFun-Passives
Package Name Conflict: Package=AXIAL-0.8 from Internal SCH lib=SparkFun  With Package=AXIAL-0.8 from LIB=SparkFun-Resistors
Package Name Conflict: Package=AXIAL-5MM from Internal SCH lib=SparkFun  With Package=AXIAL-5MM from LIB=SparkFun-Capacitors
Package Name Conflict: Package=AXIAL-5MM from Internal SCH lib=SparkFun  With Package=AXIAL-5MM from LIB=SparkFun-Passives
Package Name Conflict: Package=C0402 from Internal SCH lib=SparkFun  With Package=C0402 from LIB=SmartPrj
Package Name Conflict: Package=CAP-PTH-5MM from Internal SCH lib=SparkFun  With Package=CAP-PTH-5MM from LIB=SparkFun-Capacitors
Package Name Conflict: Package=CAP-PTH-5MM from Internal SCH lib=SparkFun  With Package=CAP-PTH-5MM from LIB=SparkFun-Passives
Package Name Conflict: Package=CAP-PTH-LARGE from Internal SCH lib=SparkFun  With Package=CAP-PTH-LARGE from LIB=SparkFun-Capacitors
Package Name Conflict: Package=CAP-PTH-LARGE from Internal SCH lib=SparkFun  With Package=CAP-PTH-LARGE from LIB=SparkFun-Passives
Package Name Conflict: Package=CAP-PTH-SMALL from Internal SCH lib=SparkFun  With Package=CAP-PTH-SMALL from LIB=SparkFun-Capacitors
Package Name Conflict: Package=CAP-PTH-SMALL from Internal SCH lib=SparkFun  With Package=CAP-PTH-SMALL from LIB=SparkFun-Passives
Package Name Conflict: Package=CAP-PTH-SMALL2 from Internal SCH lib=SparkFun  With Package=CAP-PTH-SMALL2 from LIB=SparkFun-Capacitors
Package Name Conflict: Package=CAP-PTH-SMALL2 from Internal SCH lib=SparkFun  With Package=CAP-PTH-SMALL2 from LIB=SparkFun-Passives
Package Name Conflict: Package=CPOL-RADIAL-10UF-25V from Internal SCH lib=SparkFun  With Package=CPOL-RADIAL-10UF-25V from LIB=kolosy
Package Name Conflict: Package=CPOL-RADIAL-100UF-25V from Internal SCH lib=SparkFun  With Package=CPOL-RADIAL-100UF-25V from LIB=kolosy
Package Name Conflict: Package=CPOL-RADIAL-1000UF-25V from Internal SCH lib=SparkFun  With Package=CPOL-RADIAL-1000UF-25V from LIB=kolosy
Package Name Conflict: Package=CPOL-RADIAL-1000UF-63V from Internal SCH lib=SparkFun  With Package=CPOL-RADIAL-1000UF-63V from LIB=kolosy
Package Name Conflict: Package=CTZ3 from Internal SCH lib=SparkFun  With Package=CTZ3 from LIB=SparkFun-Capacitors
Package Name Conflict: Package=CTZ3 from Internal SCH lib=SparkFun  With Package=CTZ3 from LIB=SparkFun-Passives
Package Name Conflict: Package=EIA3216 from Internal SCH lib=SparkFun  With Package=EIA3216 from LIB=kolosy
Package Name Conflict: Package=EIA3216-KIT from Internal SCH lib=SparkFun  With Package=EIA3216-KIT from LIB=kolosy
Package Name Conflict: Package=EIA3528 from Internal SCH lib=SparkFun  With Package=EIA3528 from LIB=kolosy
Package Name Conflict: Package=EIA3528-KIT from Internal SCH lib=SparkFun  With Package=EIA3528-KIT from LIB=kolosy
Package Name Conflict: Package=EIA6032 from Internal SCH lib=SparkFun  With Package=EIA6032 from LIB=kolosy
Package Name Conflict: Package=EIA7343 from Internal SCH lib=SparkFun  With Package=EIA7343 from LIB=kolosy
Package Name Conflict: Package=EN_J2 from Internal SCH lib=SparkFun  With Package=EN_J2 from LIB=kolosy
Package Name Conflict: Package=GRM43D from Internal SCH lib=SparkFun  With Package=GRM43D from LIB=SparkFun-Capacitors
Package Name Conflict: Package=GRM43D from Internal SCH lib=SparkFun  With Package=GRM43D from LIB=SparkFun-Passives
Package Name Conflict: Package=NIPPON_F80 from Internal SCH lib=SparkFun  With Package=NIPPON_F80 from LIB=kolosy
Package Name Conflict: Package=PANASONIC_C from Internal SCH lib=SparkFun  With Package=PANASONIC_C from LIB=kolosy
Package Name Conflict: Package=PANASONIC_D from Internal SCH lib=SparkFun  With Package=PANASONIC_D from LIB=kolosy
Package Name Conflict: Package=PANASONIC_E from Internal SCH lib=SparkFun  With Package=PANASONIC_E from LIB=kolosy
Package Name Conflict: Package=PANASONIC_G from Internal SCH lib=SparkFun  With Package=PANASONIC_G from LIB=kolosy
Package Name Conflict: Package=PANASONIC_H13 from Internal SCH lib=SparkFun  With Package=PANASONIC_H13 from LIB=kolosy
Package Name Conflict: Package=R2010 from Internal SCH lib=SparkFun  With Package=R2010 from LIB=SmartPrj
Package Name Conflict: Package=R2010 from Internal SCH lib=SparkFun  With Package=R2010 from LIB=SparkFun-Passives
Package Name Conflict: Package=R2010 from Internal SCH lib=SparkFun  With Package=R2010 from LIB=SparkFun-Resistors
Package Name Conflict: Package=R2512 from Internal SCH lib=SparkFun  With Package=R2512 from LIB=SmartPrj
Package Name Conflict: Package=R2512 from Internal SCH lib=SparkFun  With Package=R2512 from LIB=SparkFun-Passives
Package Name Conflict: Package=R2512 from Internal SCH lib=SparkFun  With Package=R2512 from LIB=SparkFun-Resistors
Package Name Conflict: Package=SOT23-3 from Internal SCH lib=SparkFun  With Package=SOT23-3 from LIB=SparkFun-DiscreteSemi
Package Name Conflict: Package=VISHAY_C from Internal SCH lib=SparkFun  With Package=VISHAY_C from LIB=kolosy
Device Name Conflict: Device=GND from Internal SCH lib=SparkFun-Aesthetics  With Device=GND from LIB=SparkFun
Device Name Conflict: Device=GND from Internal SCH lib=SparkFun-Aesthetics  With Device=GND from LIB=supply1
Device Name Conflict: Device=CAP0402-CAP from Internal SCH lib=SparkFun-Capacitors  With Device=CAP0402-CAP from LIB=SparkFun
Device Name Conflict: Device=CAP0402-CAP from Internal SCH lib=SparkFun-Capacitors  With Device=CAP0402-CAP from LIB=SparkFun-Passives
Device Name Conflict: Device=CAP0603-CAP from Internal SCH lib=SparkFun-Capacitors  With Device=CAP0603-CAP from LIB=SparkFun
Device Name Conflict: Device=CAP0603-CAP from Internal SCH lib=SparkFun-Capacitors  With Device=CAP0603-CAP from LIB=SparkFun-Passives
Device Name Conflict: Device=CAP0805 from Internal SCH lib=SparkFun-Capacitors  With Device=CAP0805 from LIB=SparkFun
Device Name Conflict: Device=CAP0805 from Internal SCH lib=SparkFun-Capacitors  With Device=CAP0805 from LIB=SparkFun-Passives
Device Name Conflict: Device=CAP1206 from Internal SCH lib=SparkFun-Capacitors  With Device=CAP1206 from LIB=SparkFun
Device Name Conflict: Device=CAP1206 from Internal SCH lib=SparkFun-Capacitors  With Device=CAP1206 from LIB=SparkFun-Passives
Device Name Conflict: Device=CAP1210 from Internal SCH lib=SparkFun-Capacitors  With Device=CAP1210 from LIB=SparkFun
Device Name Conflict: Device=CAP1210 from Internal SCH lib=SparkFun-Capacitors  With Device=CAP1210 from LIB=SparkFun-Passives
Device Name Conflict: Device=CAPASMD from Internal SCH lib=SparkFun-Capacitors  With Device=CAPASMD from LIB=SparkFun
Device Name Conflict: Device=CAPASMD from Internal SCH lib=SparkFun-Capacitors  With Device=CAPASMD from LIB=SparkFun-Passives
Device Name Conflict: Device=CAPKIT from Internal SCH lib=SparkFun-Capacitors  With Device=CAPKIT from LIB=SparkFun-Passives
Device Name Conflict: Device=CAPPTH from Internal SCH lib=SparkFun-Capacitors  With Device=CAPPTH from LIB=SparkFun
Device Name Conflict: Device=CAPPTH from Internal SCH lib=SparkFun-Capacitors  With Device=CAPPTH from LIB=SparkFun-Passives
Device Name Conflict: Device=CAPPTH1 from Internal SCH lib=SparkFun-Capacitors  With Device=CAPPTH1 from LIB=SparkFun
Device Name Conflict: Device=CAPPTH1 from Internal SCH lib=SparkFun-Capacitors  With Device=CAPPTH1 from LIB=SparkFun-Passives
Device Name Conflict: Device=CAPPTH2 from Internal SCH lib=SparkFun-Capacitors  With Device=CAPPTH2 from LIB=SparkFun
Device Name Conflict: Device=CAPPTH2 from Internal SCH lib=SparkFun-Capacitors  With Device=CAPPTH2 from LIB=SparkFun-Passives
Device Name Conflict: Device=CAPPTH3 from Internal SCH lib=SparkFun-Capacitors  With Device=CAPPTH3 from LIB=SparkFun
Device Name Conflict: Device=CAPPTH3 from Internal SCH lib=SparkFun-Capacitors  With Device=CAPPTH3 from LIB=SparkFun-Passives
Device Name Conflict: Device=CAPSMD from Internal SCH lib=SparkFun-Capacitors  With Device=CAPSMD from LIB=SparkFun
Device Name Conflict: Device=CAPSMD from Internal SCH lib=SparkFun-Capacitors  With Device=CAPSMD from LIB=SparkFun-Passives
Device Name Conflict: Device=CAP_ from Internal SCH lib=SparkFun-Capacitors  With Device=CAP_ from LIB=SparkFun
Device Name Conflict: Device=CAP_ from Internal SCH lib=SparkFun-Capacitors  With Device=CAP_ from LIB=SparkFun-Passives
Symbol Name Conflict: Symbol=CAP from Internal SCH lib=SparkFun-Capacitors  With Symbol=CAP from LIB=SparkFun
Symbol Name Conflict: Symbol=CAP from Internal SCH lib=SparkFun-Capacitors  With Symbol=CAP from LIB=SparkFun-Passives
Package Name Conflict: Package=0402-CAP from Internal SCH lib=SparkFun-Capacitors  With Package=0402-CAP from LIB=SparkFun
Package Name Conflict: Package=0402-CAP from Internal SCH lib=SparkFun-Capacitors  With Package=0402-CAP from LIB=SparkFun-Passives
Package Name Conflict: Package=0603-CAP from Internal SCH lib=SparkFun-Capacitors  With Package=0603-CAP from LIB=SparkFun
Package Name Conflict: Package=0603-CAP from Internal SCH lib=SparkFun-Capacitors  With Package=0603-CAP from LIB=SparkFun-Passives
Package Name Conflict: Package=0805 from Internal SCH lib=SparkFun-Capacitors  With Package=0805 from LIB=SparkFun
Package Name Conflict: Package=0805 from Internal SCH lib=SparkFun-Capacitors  With Package=0805 from LIB=SparkFun-Passives
Package Name Conflict: Package=0805 from Internal SCH lib=SparkFun-Capacitors  With Package=0805 from LIB=SparkFun-Resistors
Package Name Conflict: Package=1206 from Internal SCH lib=SparkFun-Capacitors  With Package=1206 from LIB=SparkFun
Package Name Conflict: Package=1206 from Internal SCH lib=SparkFun-Capacitors  With Package=1206 from LIB=SparkFun-Passives
Package Name Conflict: Package=1206 from Internal SCH lib=SparkFun-Capacitors  With Package=1206 from LIB=SparkFun-Resistors
Package Name Conflict: Package=1210 from Internal SCH lib=SparkFun-Capacitors  With Package=1210 from LIB=SparkFun
Package Name Conflict: Package=1210 from Internal SCH lib=SparkFun-Capacitors  With Package=1210 from LIB=SparkFun-Passives
Package Name Conflict: Package=AXIAL-5MM from Internal SCH lib=SparkFun-Capacitors  With Package=AXIAL-5MM from LIB=SparkFun
Package Name Conflict: Package=AXIAL-5MM from Internal SCH lib=SparkFun-Capacitors  With Package=AXIAL-5MM from LIB=SparkFun-Passives
Package Name Conflict: Package=CAP-PTH-5MM from Internal SCH lib=SparkFun-Capacitors  With Package=CAP-PTH-5MM from LIB=SparkFun
Package Name Conflict: Package=CAP-PTH-5MM from Internal SCH lib=SparkFun-Capacitors  With Package=CAP-PTH-5MM from LIB=SparkFun-Passives
Package Name Conflict: Package=CAP-PTH-LARGE from Internal SCH lib=SparkFun-Capacitors  With Package=CAP-PTH-LARGE from LIB=SparkFun
Package Name Conflict: Package=CAP-PTH-LARGE from Internal SCH lib=SparkFun-Capacitors  With Package=CAP-PTH-LARGE from LIB=SparkFun-Passives
Package Name Conflict: Package=CAP-PTH-SMALL from Internal SCH lib=SparkFun-Capacitors  With Package=CAP-PTH-SMALL from LIB=SparkFun
Package Name Conflict: Package=CAP-PTH-SMALL from Internal SCH lib=SparkFun-Capacitors  With Package=CAP-PTH-SMALL from LIB=SparkFun-Passives
Package Name Conflict: Package=CAP-PTH-SMALL-KIT from Internal SCH lib=SparkFun-Capacitors  With Package=CAP-PTH-SMALL-KIT from LIB=SparkFun-Passives
Package Name Conflict: Package=CAP-PTH-SMALL2 from Internal SCH lib=SparkFun-Capacitors  With Package=CAP-PTH-SMALL2 from LIB=SparkFun
Package Name Conflict: Package=CAP-PTH-SMALL2 from Internal SCH lib=SparkFun-Capacitors  With Package=CAP-PTH-SMALL2 from LIB=SparkFun-Passives
Package Name Conflict: Package=CTZ3 from Internal SCH lib=SparkFun-Capacitors  With Package=CTZ3 from LIB=SparkFun
Package Name Conflict: Package=CTZ3 from Internal SCH lib=SparkFun-Capacitors  With Package=CTZ3 from LIB=SparkFun-Passives
Package Name Conflict: Package=GRM43D from Internal SCH lib=SparkFun-Capacitors  With Package=GRM43D from LIB=SparkFun
Package Name Conflict: Package=GRM43D from Internal SCH lib=SparkFun-Capacitors  With Package=GRM43D from LIB=SparkFun-Passives
Package Name Conflict: Package=SOT23-3 from Internal SCH lib=SparkFun-DiscreteSemi  With Package=SOT23-3 from LIB=SparkFun
Device Name Conflict: Device=CAP0402-CAP from Internal SCH lib=SparkFun-Passives  With Device=CAP0402-CAP from LIB=SparkFun
Device Name Conflict: Device=CAP0402-CAP from Internal SCH lib=SparkFun-Passives  With Device=CAP0402-CAP from LIB=SparkFun-Capacitors
Device Name Conflict: Device=CAP0603-CAP from Internal SCH lib=SparkFun-Passives  With Device=CAP0603-CAP from LIB=SparkFun
Device Name Conflict: Device=CAP0603-CAP from Internal SCH lib=SparkFun-Passives  With Device=CAP0603-CAP from LIB=SparkFun-Capacitors
Device Name Conflict: Device=CAP0805 from Internal SCH lib=SparkFun-Passives  With Device=CAP0805 from LIB=SparkFun
Device Name Conflict: Device=CAP0805 from Internal SCH lib=SparkFun-Passives  With Device=CAP0805 from LIB=SparkFun-Capacitors
Device Name Conflict: Device=CAP1206 from Internal SCH lib=SparkFun-Passives  With Device=CAP1206 from LIB=SparkFun
Device Name Conflict: Device=CAP1206 from Internal SCH lib=SparkFun-Passives  With Device=CAP1206 from LIB=SparkFun-Capacitors
Device Name Conflict: Device=CAP1210 from Internal SCH lib=SparkFun-Passives  With Device=CAP1210 from LIB=SparkFun
Device Name Conflict: Device=CAP1210 from Internal SCH lib=SparkFun-Passives  With Device=CAP1210 from LIB=SparkFun-Capacitors
Device Name Conflict: Device=CAPASMD from Internal SCH lib=SparkFun-Passives  With Device=CAPASMD from LIB=SparkFun
Device Name Conflict: Device=CAPASMD from Internal SCH lib=SparkFun-Passives  With Device=CAPASMD from LIB=SparkFun-Capacitors
Device Name Conflict: Device=CAPKIT from Internal SCH lib=SparkFun-Passives  With Device=CAPKIT from LIB=SparkFun-Capacitors
Device Name Conflict: Device=CAPPTH from Internal SCH lib=SparkFun-Passives  With Device=CAPPTH from LIB=SparkFun
Device Name Conflict: Device=CAPPTH from Internal SCH lib=SparkFun-Passives  With Device=CAPPTH from LIB=SparkFun-Capacitors
Device Name Conflict: Device=CAPPTH1 from Internal SCH lib=SparkFun-Passives  With Device=CAPPTH1 from LIB=SparkFun
Device Name Conflict: Device=CAPPTH1 from Internal SCH lib=SparkFun-Passives  With Device=CAPPTH1 from LIB=SparkFun-Capacitors
Device Name Conflict: Device=CAPPTH2 from Internal SCH lib=SparkFun-Passives  With Device=CAPPTH2 from LIB=SparkFun
Device Name Conflict: Device=CAPPTH2 from Internal SCH lib=SparkFun-Passives  With Device=CAPPTH2 from LIB=SparkFun-Capacitors
Device Name Conflict: Device=CAPPTH3 from Internal SCH lib=SparkFun-Passives  With Device=CAPPTH3 from LIB=SparkFun
Device Name Conflict: Device=CAPPTH3 from Internal SCH lib=SparkFun-Passives  With Device=CAPPTH3 from LIB=SparkFun-Capacitors
Device Name Conflict: Device=CAPSMD from Internal SCH lib=SparkFun-Passives  With Device=CAPSMD from LIB=SparkFun
Device Name Conflict: Device=CAPSMD from Internal SCH lib=SparkFun-Passives  With Device=CAPSMD from LIB=SparkFun-Capacitors
Device Name Conflict: Device=CAP_ from Internal SCH lib=SparkFun-Passives  With Device=CAP_ from LIB=SparkFun
Device Name Conflict: Device=CAP_ from Internal SCH lib=SparkFun-Passives  With Device=CAP_ from LIB=SparkFun-Capacitors
Device Name Conflict: Device=RESISTOR0402-RES from Internal SCH lib=SparkFun-Passives  With Device=RESISTOR0402-RES from LIB=SparkFun
Device Name Conflict: Device=RESISTOR0603-RES from Internal SCH lib=SparkFun-Passives  With Device=RESISTOR0603-RES from LIB=SparkFun
Device Name Conflict: Device=RESISTOR0603-RES from Internal SCH lib=SparkFun-Passives  With Device=RESISTOR0603-RES from LIB=SparkFun-Resistors
Device Name Conflict: Device=RESISTOR0805-RES from Internal SCH lib=SparkFun-Passives  With Device=RESISTOR0805-RES from LIB=SparkFun
Device Name Conflict: Device=RESISTOR0805-RES from Internal SCH lib=SparkFun-Passives  With Device=RESISTOR0805-RES from LIB=SparkFun-Resistors
Device Name Conflict: Device=RESISTOR1206 from Internal SCH lib=SparkFun-Passives  With Device=RESISTOR1206 from LIB=SparkFun
Device Name Conflict: Device=RESISTOR1206 from Internal SCH lib=SparkFun-Passives  With Device=RESISTOR1206 from LIB=SparkFun-Resistors
Device Name Conflict: Device=RESISTOR2010 from Internal SCH lib=SparkFun-Passives  With Device=RESISTOR2010 from LIB=SparkFun
Device Name Conflict: Device=RESISTOR2010 from Internal SCH lib=SparkFun-Passives  With Device=RESISTOR2010 from LIB=SparkFun-Resistors
Device Name Conflict: Device=RESISTOR2512 from Internal SCH lib=SparkFun-Passives  With Device=RESISTOR2512 from LIB=SparkFun
Device Name Conflict: Device=RESISTOR2512 from Internal SCH lib=SparkFun-Passives  With Device=RESISTOR2512 from LIB=SparkFun-Resistors
Device Name Conflict: Device=RESISTORAXIAL-0.3 from Internal SCH lib=SparkFun-Passives  With Device=RESISTORAXIAL-0.3 from LIB=SparkFun
Device Name Conflict: Device=RESISTORAXIAL-0.3 from Internal SCH lib=SparkFun-Passives  With Device=RESISTORAXIAL-0.3 from LIB=SparkFun-Resistors
Device Name Conflict: Device=RESISTOREZ from Internal SCH lib=SparkFun-Passives  With Device=RESISTOREZ from LIB=SparkFun-Resistors
Device Name Conflict: Device=RESISTORKIT from Internal SCH lib=SparkFun-Passives  With Device=RESISTORKIT from LIB=SparkFun-Resistors
Device Name Conflict: Device=RESISTORPTH-1/2W from Internal SCH lib=SparkFun-Passives  With Device=RESISTORPTH-1/2W from LIB=SparkFun
Device Name Conflict: Device=RESISTORPTH-1/2W from Internal SCH lib=SparkFun-Passives  With Device=RESISTORPTH-1/2W from LIB=SparkFun-Resistors
Device Name Conflict: Device=RESISTORPTH-1/4W from Internal SCH lib=SparkFun-Passives  With Device=RESISTORPTH-1/4W from LIB=SparkFun
Device Name Conflict: Device=RESISTORPTH-1/4W from Internal SCH lib=SparkFun-Passives  With Device=RESISTORPTH-1/4W from LIB=SparkFun-Resistors
Device Name Conflict: Device=RESISTORPTH-1/6W from Internal SCH lib=SparkFun-Passives  With Device=RESISTORPTH-1/6W from LIB=SparkFun
Device Name Conflict: Device=RESISTORPTH-1/6W from Internal SCH lib=SparkFun-Passives  With Device=RESISTORPTH-1/6W from LIB=SparkFun-Resistors
Device Name Conflict: Device=RESISTORPTH-1W from Internal SCH lib=SparkFun-Passives  With Device=RESISTORPTH-1W from LIB=SparkFun
Device Name Conflict: Device=RESISTORPTH-1W from Internal SCH lib=SparkFun-Passives  With Device=RESISTORPTH-1W from LIB=SparkFun-Resistors
Device Name Conflict: Device=RESISTORPTH-2W from Internal SCH lib=SparkFun-Passives  With Device=RESISTORPTH-2W from LIB=SparkFun
Device Name Conflict: Device=RESISTORPTH-2W from Internal SCH lib=SparkFun-Passives  With Device=RESISTORPTH-2W from LIB=SparkFun-Resistors
Symbol Name Conflict: Symbol=CAP from Internal SCH lib=SparkFun-Passives  With Symbol=CAP from LIB=SparkFun
Symbol Name Conflict: Symbol=CAP from Internal SCH lib=SparkFun-Passives  With Symbol=CAP from LIB=SparkFun-Capacitors
Symbol Name Conflict: Symbol=RESISTOR from Internal SCH lib=SparkFun-Passives  With Symbol=RESISTOR from LIB=SparkFun
Symbol Name Conflict: Symbol=RESISTOR from Internal SCH lib=SparkFun-Passives  With Symbol=RESISTOR from LIB=SparkFun-Resistors
Package Name Conflict: Package=1/6W-RES from Internal SCH lib=SparkFun-Passives  With Package=1/6W-RES from LIB=SparkFun
Package Name Conflict: Package=1/6W-RES from Internal SCH lib=SparkFun-Passives  With Package=1/6W-RES from LIB=SparkFun-Resistors
Package Name Conflict: Package=0402-CAP from Internal SCH lib=SparkFun-Passives  With Package=0402-CAP from LIB=SparkFun
Package Name Conflict: Package=0402-CAP from Internal SCH lib=SparkFun-Passives  With Package=0402-CAP from LIB=SparkFun-Capacitors
Package Name Conflict: Package=0402-RES from Internal SCH lib=SparkFun-Passives  With Package=0402-RES from LIB=SparkFun
Package Name Conflict: Package=0603-CAP from Internal SCH lib=SparkFun-Passives  With Package=0603-CAP from LIB=SparkFun
Package Name Conflict: Package=0603-CAP from Internal SCH lib=SparkFun-Passives  With Package=0603-CAP from LIB=SparkFun-Capacitors
Package Name Conflict: Package=0603-RES from Internal SCH lib=SparkFun-Passives  With Package=0603-RES from LIB=SparkFun
Package Name Conflict: Package=0603-RES from Internal SCH lib=SparkFun-Passives  With Package=0603-RES from LIB=SparkFun-Resistors
Package Name Conflict: Package=0805 from Internal SCH lib=SparkFun-Passives  With Package=0805 from LIB=SparkFun
Package Name Conflict: Package=0805 from Internal SCH lib=SparkFun-Passives  With Package=0805 from LIB=SparkFun-Capacitors
Package Name Conflict: Package=0805 from Internal SCH lib=SparkFun-Passives  With Package=0805 from LIB=SparkFun-Resistors
Package Name Conflict: Package=1206 from Internal SCH lib=SparkFun-Passives  With Package=1206 from LIB=SparkFun
Package Name Conflict: Package=1206 from Internal SCH lib=SparkFun-Passives  With Package=1206 from LIB=SparkFun-Capacitors
Package Name Conflict: Package=1206 from Internal SCH lib=SparkFun-Passives  With Package=1206 from LIB=SparkFun-Resistors
Package Name Conflict: Package=1210 from Internal SCH lib=SparkFun-Passives  With Package=1210 from LIB=SparkFun
Package Name Conflict: Package=1210 from Internal SCH lib=SparkFun-Passives  With Package=1210 from LIB=SparkFun-Capacitors
Package Name Conflict: Package=AXIAL-0.3 from Internal SCH lib=SparkFun-Passives  With Package=AXIAL-0.3 from LIB=SparkFun
Package Name Conflict: Package=AXIAL-0.3 from Internal SCH lib=SparkFun-Passives  With Package=AXIAL-0.3 from LIB=SparkFun-Resistors
Package Name Conflict: Package=AXIAL-0.3-KIT from Internal SCH lib=SparkFun-Passives  With Package=AXIAL-0.3-KIT from LIB=SparkFun-Resistors
Package Name Conflict: Package=AXIAL-0.3EZ from Internal SCH lib=SparkFun-Passives  With Package=AXIAL-0.3EZ from LIB=SparkFun-Resistors
Package Name Conflict: Package=AXIAL-0.4 from Internal SCH lib=SparkFun-Passives  With Package=AXIAL-0.4 from LIB=SparkFun
Package Name Conflict: Package=AXIAL-0.4 from Internal SCH lib=SparkFun-Passives  With Package=AXIAL-0.4 from LIB=SparkFun-Resistors
Package Name Conflict: Package=AXIAL-0.5 from Internal SCH lib=SparkFun-Passives  With Package=AXIAL-0.5 from LIB=SparkFun
Package Name Conflict: Package=AXIAL-0.5 from Internal SCH lib=SparkFun-Passives  With Package=AXIAL-0.5 from LIB=SparkFun-Resistors
Package Name Conflict: Package=AXIAL-0.6 from Internal SCH lib=SparkFun-Passives  With Package=AXIAL-0.6 from LIB=SparkFun
Package Name Conflict: Package=AXIAL-0.6 from Internal SCH lib=SparkFun-Passives  With Package=AXIAL-0.6 from LIB=SparkFun-Resistors
Package Name Conflict: Package=AXIAL-0.8 from Internal SCH lib=SparkFun-Passives  With Package=AXIAL-0.8 from LIB=SparkFun
Package Name Conflict: Package=AXIAL-0.8 from Internal SCH lib=SparkFun-Passives  With Package=AXIAL-0.8 from LIB=SparkFun-Resistors
Package Name Conflict: Package=AXIAL-5MM from Internal SCH lib=SparkFun-Passives  With Package=AXIAL-5MM from LIB=SparkFun
Package Name Conflict: Package=AXIAL-5MM from Internal SCH lib=SparkFun-Passives  With Package=AXIAL-5MM from LIB=SparkFun-Capacitors
Package Name Conflict: Package=CAP-PTH-5MM from Internal SCH lib=SparkFun-Passives  With Package=CAP-PTH-5MM from LIB=SparkFun
Package Name Conflict: Package=CAP-PTH-5MM from Internal SCH lib=SparkFun-Passives  With Package=CAP-PTH-5MM from LIB=SparkFun-Capacitors
Package Name Conflict: Package=CAP-PTH-LARGE from Internal SCH lib=SparkFun-Passives  With Package=CAP-PTH-LARGE from LIB=SparkFun
Package Name Conflict: Package=CAP-PTH-LARGE from Internal SCH lib=SparkFun-Passives  With Package=CAP-PTH-LARGE from LIB=SparkFun-Capacitors
Package Name Conflict: Package=CAP-PTH-SMALL from Internal SCH lib=SparkFun-Passives  With Package=CAP-PTH-SMALL from LIB=SparkFun
Package Name Conflict: Package=CAP-PTH-SMALL from Internal SCH lib=SparkFun-Passives  With Package=CAP-PTH-SMALL from LIB=SparkFun-Capacitors
Package Name Conflict: Package=CAP-PTH-SMALL-KIT from Internal SCH lib=SparkFun-Passives  With Package=CAP-PTH-SMALL-KIT from LIB=SparkFun-Capacitors
Package Name Conflict: Package=CAP-PTH-SMALL2 from Internal SCH lib=SparkFun-Passives  With Package=CAP-PTH-SMALL2 from LIB=SparkFun
Package Name Conflict: Package=CAP-PTH-SMALL2 from Internal SCH lib=SparkFun-Passives  With Package=CAP-PTH-SMALL2 from LIB=SparkFun-Capacitors
Package Name Conflict: Package=CTZ3 from Internal SCH lib=SparkFun-Passives  With Package=CTZ3 from LIB=SparkFun
Package Name Conflict: Package=CTZ3 from Internal SCH lib=SparkFun-Passives  With Package=CTZ3 from LIB=SparkFun-Capacitors
Package Name Conflict: Package=GRM43D from Internal SCH lib=SparkFun-Passives  With Package=GRM43D from LIB=SparkFun
Package Name Conflict: Package=GRM43D from Internal SCH lib=SparkFun-Passives  With Package=GRM43D from LIB=SparkFun-Capacitors
Package Name Conflict: Package=R2010 from Internal SCH lib=SparkFun-Passives  With Package=R2010 from LIB=SmartPrj
Package Name Conflict: Package=R2010 from Internal SCH lib=SparkFun-Passives  With Package=R2010 from LIB=SparkFun
Package Name Conflict: Package=R2010 from Internal SCH lib=SparkFun-Passives  With Package=R2010 from LIB=SparkFun-Resistors
Package Name Conflict: Package=R2512 from Internal SCH lib=SparkFun-Passives  With Package=R2512 from LIB=SmartPrj
Package Name Conflict: Package=R2512 from Internal SCH lib=SparkFun-Passives  With Package=R2512 from LIB=SparkFun
Package Name Conflict: Package=R2512 from Internal SCH lib=SparkFun-Passives  With Package=R2512 from LIB=SparkFun-Resistors
Device Name Conflict: Device=RESISTOR0603-RES from Internal SCH lib=SparkFun-Resistors  With Device=RESISTOR0603-RES from LIB=SparkFun
Device Name Conflict: Device=RESISTOR0603-RES from Internal SCH lib=SparkFun-Resistors  With Device=RESISTOR0603-RES from LIB=SparkFun-Passives
Device Name Conflict: Device=RESISTOR0805-RES from Internal SCH lib=SparkFun-Resistors  With Device=RESISTOR0805-RES from LIB=SparkFun
Device Name Conflict: Device=RESISTOR0805-RES from Internal SCH lib=SparkFun-Resistors  With Device=RESISTOR0805-RES from LIB=SparkFun-Passives
Device Name Conflict: Device=RESISTOR1206 from Internal SCH lib=SparkFun-Resistors  With Device=RESISTOR1206 from LIB=SparkFun
Device Name Conflict: Device=RESISTOR1206 from Internal SCH lib=SparkFun-Resistors  With Device=RESISTOR1206 from LIB=SparkFun-Passives
Device Name Conflict: Device=RESISTOR2010 from Internal SCH lib=SparkFun-Resistors  With Device=RESISTOR2010 from LIB=SparkFun
Device Name Conflict: Device=RESISTOR2010 from Internal SCH lib=SparkFun-Resistors  With Device=RESISTOR2010 from LIB=SparkFun-Passives
Device Name Conflict: Device=RESISTOR2512 from Internal SCH lib=SparkFun-Resistors  With Device=RESISTOR2512 from LIB=SparkFun
Device Name Conflict: Device=RESISTOR2512 from Internal SCH lib=SparkFun-Resistors  With Device=RESISTOR2512 from LIB=SparkFun-Passives
Device Name Conflict: Device=RESISTORAXIAL-0.3 from Internal SCH lib=SparkFun-Resistors  With Device=RESISTORAXIAL-0.3 from LIB=SparkFun
Device Name Conflict: Device=RESISTORAXIAL-0.3 from Internal SCH lib=SparkFun-Resistors  With Device=RESISTORAXIAL-0.3 from LIB=SparkFun-Passives
Device Name Conflict: Device=RESISTOREZ from Internal SCH lib=SparkFun-Resistors  With Device=RESISTOREZ from LIB=SparkFun-Passives
Device Name Conflict: Device=RESISTORKIT from Internal SCH lib=SparkFun-Resistors  With Device=RESISTORKIT from LIB=SparkFun-Passives
Device Name Conflict: Device=RESISTORPTH-1/2W from Internal SCH lib=SparkFun-Resistors  With Device=RESISTORPTH-1/2W from LIB=SparkFun
Device Name Conflict: Device=RESISTORPTH-1/2W from Internal SCH lib=SparkFun-Resistors  With Device=RESISTORPTH-1/2W from LIB=SparkFun-Passives
Device Name Conflict: Device=RESISTORPTH-1/4W from Internal SCH lib=SparkFun-Resistors  With Device=RESISTORPTH-1/4W from LIB=SparkFun
Device Name Conflict: Device=RESISTORPTH-1/4W from Internal SCH lib=SparkFun-Resistors  With Device=RESISTORPTH-1/4W from LIB=SparkFun-Passives
Device Name Conflict: Device=RESISTORPTH-1/6W from Internal SCH lib=SparkFun-Resistors  With Device=RESISTORPTH-1/6W from LIB=SparkFun
Device Name Conflict: Device=RESISTORPTH-1/6W from Internal SCH lib=SparkFun-Resistors  With Device=RESISTORPTH-1/6W from LIB=SparkFun-Passives
Device Name Conflict: Device=RESISTORPTH-1W from Internal SCH lib=SparkFun-Resistors  With Device=RESISTORPTH-1W from LIB=SparkFun
Device Name Conflict: Device=RESISTORPTH-1W from Internal SCH lib=SparkFun-Resistors  With Device=RESISTORPTH-1W from LIB=SparkFun-Passives
Device Name Conflict: Device=RESISTORPTH-2W from Internal SCH lib=SparkFun-Resistors  With Device=RESISTORPTH-2W from LIB=SparkFun
Device Name Conflict: Device=RESISTORPTH-2W from Internal SCH lib=SparkFun-Resistors  With Device=RESISTORPTH-2W from LIB=SparkFun-Passives
Symbol Name Conflict: Symbol=RESISTOR from Internal SCH lib=SparkFun-Resistors  With Symbol=RESISTOR from LIB=SparkFun
Symbol Name Conflict: Symbol=RESISTOR from Internal SCH lib=SparkFun-Resistors  With Symbol=RESISTOR from LIB=SparkFun-Passives
Package Name Conflict: Package=1/6W-RES from Internal SCH lib=SparkFun-Resistors  With Package=1/6W-RES from LIB=SparkFun
Package Name Conflict: Package=1/6W-RES from Internal SCH lib=SparkFun-Resistors  With Package=1/6W-RES from LIB=SparkFun-Passives
Package Name Conflict: Package=0603-RES from Internal SCH lib=SparkFun-Resistors  With Package=0603-RES from LIB=SparkFun
Package Name Conflict: Package=0603-RES from Internal SCH lib=SparkFun-Resistors  With Package=0603-RES from LIB=SparkFun-Passives
Package Name Conflict: Package=0805 from Internal SCH lib=SparkFun-Resistors  With Package=0805 from LIB=SparkFun
Package Name Conflict: Package=0805 from Internal SCH lib=SparkFun-Resistors  With Package=0805 from LIB=SparkFun-Capacitors
Package Name Conflict: Package=0805 from Internal SCH lib=SparkFun-Resistors  With Package=0805 from LIB=SparkFun-Passives
Package Name Conflict: Package=1206 from Internal SCH lib=SparkFun-Resistors  With Package=1206 from LIB=SparkFun
Package Name Conflict: Package=1206 from Internal SCH lib=SparkFun-Resistors  With Package=1206 from LIB=SparkFun-Capacitors
Package Name Conflict: Package=1206 from Internal SCH lib=SparkFun-Resistors  With Package=1206 from LIB=SparkFun-Passives
Package Name Conflict: Package=AXIAL-0.3 from Internal SCH lib=SparkFun-Resistors  With Package=AXIAL-0.3 from LIB=SparkFun
Package Name Conflict: Package=AXIAL-0.3 from Internal SCH lib=SparkFun-Resistors  With Package=AXIAL-0.3 from LIB=SparkFun-Passives
Package Name Conflict: Package=AXIAL-0.3-KIT from Internal SCH lib=SparkFun-Resistors  With Package=AXIAL-0.3-KIT from LIB=SparkFun-Passives
Package Name Conflict: Package=AXIAL-0.3EZ from Internal SCH lib=SparkFun-Resistors  With Package=AXIAL-0.3EZ from LIB=SparkFun-Passives
Package Name Conflict: Package=AXIAL-0.4 from Internal SCH lib=SparkFun-Resistors  With Package=AXIAL-0.4 from LIB=SparkFun
Package Name Conflict: Package=AXIAL-0.4 from Internal SCH lib=SparkFun-Resistors  With Package=AXIAL-0.4 from LIB=SparkFun-Passives
Package Name Conflict: Package=AXIAL-0.5 from Internal SCH lib=SparkFun-Resistors  With Package=AXIAL-0.5 from LIB=SparkFun
Package Name Conflict: Package=AXIAL-0.5 from Internal SCH lib=SparkFun-Resistors  With Package=AXIAL-0.5 from LIB=SparkFun-Passives
Package Name Conflict: Package=AXIAL-0.6 from Internal SCH lib=SparkFun-Resistors  With Package=AXIAL-0.6 from LIB=SparkFun
Package Name Conflict: Package=AXIAL-0.6 from Internal SCH lib=SparkFun-Resistors  With Package=AXIAL-0.6 from LIB=SparkFun-Passives
Package Name Conflict: Package=AXIAL-0.8 from Internal SCH lib=SparkFun-Resistors  With Package=AXIAL-0.8 from LIB=SparkFun
Package Name Conflict: Package=AXIAL-0.8 from Internal SCH lib=SparkFun-Resistors  With Package=AXIAL-0.8 from LIB=SparkFun-Passives
Package Name Conflict: Package=R2010 from Internal SCH lib=SparkFun-Resistors  With Package=R2010 from LIB=SmartPrj
Package Name Conflict: Package=R2010 from Internal SCH lib=SparkFun-Resistors  With Package=R2010 from LIB=SparkFun
Package Name Conflict: Package=R2010 from Internal SCH lib=SparkFun-Resistors  With Package=R2010 from LIB=SparkFun-Passives
Package Name Conflict: Package=R2512 from Internal SCH lib=SparkFun-Resistors  With Package=R2512 from LIB=SmartPrj
Package Name Conflict: Package=R2512 from Internal SCH lib=SparkFun-Resistors  With Package=R2512 from LIB=SparkFun
Package Name Conflict: Package=R2512 from Internal SCH lib=SparkFun-Resistors  With Package=R2512 from LIB=SparkFun-Passives
Device Name Conflict: Device=CAP_POL1206 from Internal SCH lib=kolosy  With Device=CAP_POL1206 from LIB=SparkFun
Device Name Conflict: Device=CAP_POL1206-KIT from Internal SCH lib=kolosy  With Device=CAP_POL1206-KIT from LIB=SparkFun
Device Name Conflict: Device=CAP_POL3528 from Internal SCH lib=kolosy  With Device=CAP_POL3528 from LIB=SparkFun
Device Name Conflict: Device=CAP_POL3528-KIT from Internal SCH lib=kolosy  With Device=CAP_POL3528-KIT from LIB=SparkFun
Device Name Conflict: Device=CAP_POL6032 from Internal SCH lib=kolosy  With Device=CAP_POL6032 from LIB=SparkFun
Device Name Conflict: Device=CAP_POL7343 from Internal SCH lib=kolosy  With Device=CAP_POL7343 from LIB=SparkFun
Device Name Conflict: Device=CAP_POLC from Internal SCH lib=kolosy  With Device=CAP_POLC from LIB=SparkFun
Device Name Conflict: Device=CAP_POLD from Internal SCH lib=kolosy  With Device=CAP_POLD from LIB=SparkFun
Device Name Conflict: Device=CAP_POLE from Internal SCH lib=kolosy  With Device=CAP_POLE from LIB=SparkFun
Device Name Conflict: Device=CAP_POLEN_J2 from Internal SCH lib=kolosy  With Device=CAP_POLEN_J2 from LIB=SparkFun
Device Name Conflict: Device=CAP_POLF80 from Internal SCH lib=kolosy  With Device=CAP_POLF80 from LIB=SparkFun
Device Name Conflict: Device=CAP_POLG from Internal SCH lib=kolosy  With Device=CAP_POLG from LIB=SparkFun
Device Name Conflict: Device=CAP_POLH13 from Internal SCH lib=kolosy  With Device=CAP_POLH13 from LIB=SparkFun
Device Name Conflict: Device=CAP_POLPTH1 from Internal SCH lib=kolosy  With Device=CAP_POLPTH1 from LIB=SparkFun
Device Name Conflict: Device=CAP_POLPTH2 from Internal SCH lib=kolosy  With Device=CAP_POLPTH2 from LIB=SparkFun
Device Name Conflict: Device=CAP_POLPTH3 from Internal SCH lib=kolosy  With Device=CAP_POLPTH3 from LIB=SparkFun
Device Name Conflict: Device=CAP_POLPTH4 from Internal SCH lib=kolosy  With Device=CAP_POLPTH4 from LIB=SparkFun
Device Name Conflict: Device=CAP_POLSMD from Internal SCH lib=kolosy  With Device=CAP_POLSMD from LIB=SparkFun
Symbol Name Conflict: Symbol=CAP_POL from Internal SCH lib=kolosy  With Symbol=CAP_POL from LIB=SparkFun
Package Name Conflict: Package=CPOL-RADIAL-10UF-25V from Internal SCH lib=kolosy  With Package=CPOL-RADIAL-10UF-25V from LIB=SparkFun
Package Name Conflict: Package=CPOL-RADIAL-100UF-25V from Internal SCH lib=kolosy  With Package=CPOL-RADIAL-100UF-25V from LIB=SparkFun
Package Name Conflict: Package=CPOL-RADIAL-1000UF-25V from Internal SCH lib=kolosy  With Package=CPOL-RADIAL-1000UF-25V from LIB=SparkFun
Package Name Conflict: Package=CPOL-RADIAL-1000UF-63V from Internal SCH lib=kolosy  With Package=CPOL-RADIAL-1000UF-63V from LIB=SparkFun
Package Name Conflict: Package=EIA3216 from Internal SCH lib=kolosy  With Package=EIA3216 from LIB=SparkFun
Package Name Conflict: Package=EIA3216-KIT from Internal SCH lib=kolosy  With Package=EIA3216-KIT from LIB=SparkFun
Package Name Conflict: Package=EIA3528 from Internal SCH lib=kolosy  With Package=EIA3528 from LIB=SparkFun
Package Name Conflict: Package=EIA3528-KIT from Internal SCH lib=kolosy  With Package=EIA3528-KIT from LIB=SparkFun
Package Name Conflict: Package=EIA6032 from Internal SCH lib=kolosy  With Package=EIA6032 from LIB=SparkFun
Package Name Conflict: Package=EIA7343 from Internal SCH lib=kolosy  With Package=EIA7343 from LIB=SparkFun
Package Name Conflict: Package=EN_J2 from Internal SCH lib=kolosy  With Package=EN_J2 from LIB=SparkFun
Package Name Conflict: Package=NIPPON_F80 from Internal SCH lib=kolosy  With Package=NIPPON_F80 from LIB=SparkFun
Package Name Conflict: Package=PANASONIC_C from Internal SCH lib=kolosy  With Package=PANASONIC_C from LIB=SparkFun
Package Name Conflict: Package=PANASONIC_D from Internal SCH lib=kolosy  With Package=PANASONIC_D from LIB=SparkFun
Package Name Conflict: Package=PANASONIC_E from Internal SCH lib=kolosy  With Package=PANASONIC_E from LIB=SparkFun
Package Name Conflict: Package=PANASONIC_G from Internal SCH lib=kolosy  With Package=PANASONIC_G from LIB=SparkFun
Package Name Conflict: Package=PANASONIC_H13 from Internal SCH lib=kolosy  With Package=PANASONIC_H13 from LIB=SparkFun
Package Name Conflict: Package=VISHAY_C from Internal SCH lib=kolosy  With Package=VISHAY_C from LIB=SparkFun
Device Name Conflict: Device=GND from Internal SCH lib=supply1  With Device=GND from LIB=SparkFun
Device Name Conflict: Device=GND from Internal SCH lib=supply1  With Device=GND from LIB=SparkFun-Aesthetics
Symbol Name Conflict: Symbol=GND from Internal SCH lib=supply1  With Symbol=GND from LIB=SparkFun
#********** END OF eagle6xx-sch-to-kicad-sch.ulp 1.9 05-09-2016 :21:46:51 LOG **********#

#********** START OF exp-lbrs.ulp 6.6 05-09-2016 :21:47:15 LOG **********#
OK: Eagle lib export from SCH/PCB OK
    Conversion completed with no Messages
#********** END OF exp-lbrs.ulp 6.6 05-09-2016 :21:47:15 LOG **********#

#********** START OF eagle-lbr2kicad-1.0.ulp 2.3 05-09-2016 :21:48:16 LOG **********#
Missing Prefix Part =''				KOLOSY_MICROSMP					boat6		M
Missing Prefix Part =''				KOLOSY_SOT23-6					boat6		M
Missing Prefix Part =''				KOLOSY_S-PWSON-N8					boat6		M
Missing Prefix Part =SMD				SPARKFUN_16LPCC					boat6		M
Missing Prefix Part =L				SPARKFUN_OSHW-LOGO-L					boat6		M
Missing Prefix Part =M				SPARKFUN_OSHW-LOGO-M					boat6		M
Missing Prefix Part =S				SPARKFUN_OSHW-LOGO-S					boat6		M
#********** END OF eagle-lbr2kicad-1.0.ulp 2.3 05-09-2016 :21:48:16 LOG **********#

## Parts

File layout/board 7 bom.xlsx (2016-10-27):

Kit Qty | Shrinkage | 2 | Value | Device | Package | Parts | DigiKey | Search Link | Description MF MPN OC_FARNELL OC_NEWARK PROD_ID VALUE
1 | 10 | 20 | 330 | RESISTOR0603-RES | 0603-RES | R6 | 311-330GRCT-ND | http://www.digikey.com/product-search/en?keywords=311-330GRCT-ND | Resistor
2 | 10 | 40 | .1uF | CAP0805 | 805 | C19, C32 | 445-8183-1-ND | http://www.digikey.com/product-search/en?keywords=445-8183-1-ND | Capacitor
1 | 10 | 20 | 0.05R | RESISTOR1206 | 1206 | R35 | 311-.05LYCT-ND | http://www.digikey.com/product-search/en?keywords=311-.05LYCT-ND | Resistor
1 | 10 | 20 | 0.1R | RESISTOR1206 | 1206 | R34 | 989-1031-1-ND | http://www.digikey.com/product-search/en?keywords=989-1031-1-ND | Resistor
9 | 1.5 | 27 | 0.1uF | CAP0603-CAP | 0603-CAP | C5, C10, C29, C1, C2, C11, C12, C14, C15 | 445-8136-1-ND | http://www.digikey.com/product-search/en?keywords=445-8136-1-ND | Capacitor
1 | 5 | 10 | 1.8M | RESISTOR0603 | 0603-RES | R16 | 311-1.8MGRCT-ND | http://www.digikey.com/product-search/en?keywords=311-1.8MGRCT-ND | Resistor
11 | 1.5 | 33 | 100K | RESISTOR0603 | 0603-RES | R11, R32, R100, R1, R2, R18, R19, R20, R21, R27, R36 | 311-100KGRCT-ND | http://www.digikey.com/product-search/en?keywords=311-100KGRCT-ND | Resistor
9 | 1.5 | 27 | 100R | RESISTOR0603 | 0603-RES | R8, R9, R10, R22, R23, R24, R25, R26, R37 | 311-100GRCT-ND | http://www.digikey.com/product-search/en?keywords=311-100GRCT-ND | Resistor
1 | 10 | 20 | 100uF | CAP1210 | 1210 | C26 | 587-3152-1-ND | http://www.digikey.com/product-search/en?keywords=587-3152-1-ND | Capacitor
1 | 10 | 20 | 105K | RESISTOR0603 | 0603-RES | R30 | P105KHCT-ND | http://www.digikey.com/product-search/en?keywords=P105KHCT-ND | Resistor
1 | 10 | 20 | 10K | 4R-NCAT16 | CAT16 | RN1 | CAT16-103J4LFCT-ND | http://www.digikey.com/product-search/en?keywords=CAT16-103J4LFCT-ND | Array Chip Resistor unknown unknown
5 | 1.5 | 15 | 10K | RESISTOR0603 | 0603-RES | R15, R28, R13, R4, R40 | P10.0KHCT-ND | http://www.digikey.com/product-search/en?keywords=P10.0KHCT-ND | Resistor
1 | 10 | 20 | 10nF | CAP0603-CAP | 0603-CAP | C28 | 445-1311-1-ND | http://www.digikey.com/product-search/en?keywords=445-1311-1-ND | Capacitor
1 | 10 | 20 | 10uF | CAP_POL1206 | EIA3216 | C6 | 718-1969-1-ND | http://www.digikey.com/product-search/en?keywords=718-1969-1-ND | Capacitor Polarized
1 | 10 | 20 | 10uF | CAP0805 | 805 | C21 | 445-14387-1-ND | http://www.digikey.com/product-search/en?keywords=445-14387-1-ND | Capacitor
1 | 10 | 20 | 10uF | CAP1210 | 1210 | C27 | 445-1434-1-ND | http://www.digikey.com/product-search/en?keywords=445-1434-1-ND | Capacitor
1 | 10 | 20 | 15uH | VLCF4020 | VLCF4020 | L2 | 445-3187-1-ND | http://www.digikey.com/product-search/en?keywords=445-3187-1-ND
1 | 10 | 20 | 178K | RESISTOR0603 | 0603-RES | R33 | P178KDBCT-ND | http://www.digikey.com/product-search/en?keywords=P178KDBCT-ND | Resistor
1 | 10 | 20 | 1M | R-EU_R0603 | R0603-ROUND | R12 | RHM1.00MAYCT-ND | http://www.digikey.com/product-search/en?keywords=RHM1.00MAYCT-ND | RESISTOR, European symbol
1 | 10 | 20 | 1N4148 | 1N4148 | MINIMELF | D2 | DL4148-TPMSCT-ND | http://www.digikey.com/product-search/en?keywords=DL4148-TPMSCT-ND | DIODE
1 | 10 | 20 | 1nF | CAP0402-CAP | 0402-CAP | C33 | 445-8083-1-ND | http://www.digikey.com/product-search/en?keywords=445-8083-1-ND | Capacitor
1 | 10 | 20 | 1nF | CAP0805 | 805 | C18 | 399-7987-1-ND | http://www.digikey.com/product-search/en?keywords=399-7987-1-ND | Capacitor
1 | 10 | 20 | 1uF | CAP0603-CAP | 0603-CAP | C7 | 445-1604-1-ND | http://www.digikey.com/product-search/en?keywords=445-1604-1-ND | Capacitor
1 | 10 | 20 | 1uF | CAP0805 | 805 | C25 | 490-1695-1-ND | http://www.digikey.com/product-search/en?keywords=490-1695-1-ND | Capacitor
4 | 1.5 | 12 | 200mA/50V | MOSFET-NCHANNELBSS138 | SOT23-3 | Q1, Q5, Q6, Q7 | SSM3K329RLFCT-ND | http://www.digikey.com/product-search/en?keywords=SSM3K329RLFCT-ND | Common NMOSFET Parts TRANS-00830 200mA/50V
1 | 10 | 20 | 22nF | CAP0805 | 805 | C35 | 445-1345-1-ND | http://www.digikey.com/product-search/en?keywords=445-1345-1-ND | Capacitor
2 | 10 | 40 | 22pF | C-EU0603-RND | C0603-ROUND | C16, C8 | 445-1273-1-ND | http://www.digikey.com/product-search/en?keywords=445-1273-1-ND | CAPACITOR, European symbol
1 | 10 | 20 | 22uF | CAP0805 | 805 | C22 | 445-14374-1-ND | http://www.digikey.com/product-search/en?keywords=445-14374-1-ND | Capacitor
3 | 5 | 30 | 22uF | CAP1206 | 1206 | C17, C20, C31 | 1276-3047-1-ND | http://www.digikey.com/product-search/en?keywords=1276-3047-1-ND | Capacitor
1 | 10 | 20 | 280K | RESISTOR0603 | 0603-RES | R31 | 311-280KHRCT-ND | http://www.digikey.com/product-search/en?keywords=311-280KHRCT-ND | Resistor
1 | 10 | 20 | 324K | RESISTOR0603-RES | 0603-RES | R5 | 311-324KHRCT-ND | http://www.digikey.com/product-search/en?keywords=311-324KHRCT-ND | Resistor
1 | 10 | 20 | 33k | RESISTOR0603-RES | 0603-RES | R3 | 311-33KGRCT-ND | http://www.digikey.com/product-search/en?keywords=311-33KGRCT-ND | Resistor
1 | 10 | 20 | 33nH | INDUCTOR0603 | 603 | L1 | 712-1440-1-ND | http://www.digikey.com/product-search/en?keywords=712-1440-1-ND | Inductors
1 | 10 | 20 | 4.7uF | CAP1206 | 1206 | C23 | 490-6521-1-ND | http://www.digikey.com/product-search/en?keywords=490-6521-1-ND | Capacitor
1 | 10 | 20 | 4.7uH | SLF60287055 | SLF7055 | L3 | 445-4563-1-ND | http://www.digikey.com/product-search/en?keywords=445-4563-1-ND
1 | 1 | 2 | 4700uF | CAPPTH1 | CAP-PTH-5MM | C13 | P5130-ND | http://www.digikey.com/product-search/en?keywords=P5130-ND | Capacitor
3 | 1 | 6 | 470uF | CAPPTH1 | CAP-PTH-5MM | C34, C36, C9 | 338-1703-ND | http://www.digikey.com/product-search/en?keywords=338-1703-ND | Capacitor
1 | 10 | 20 | 510K | RESISTOR0603 | 0603-RES | R29 | P510KHCT-ND | http://www.digikey.com/product-search/en?keywords=P510KHCT-ND | Resistor
1 | 10 | 20 | 56.8K | RESISTOR0603 | 0603-RES | R14 | 311-56.2KHRCT-ND | http://www.digikey.com/product-search/en?keywords=311-56.2KHRCT-ND | Resistor
1 | 10 | 20 | 576k | RESISTOR0603 | 0603-RES | R17 | 311-576KHRCT-ND | http://www.digikey.com/product-search/en?keywords=311-576KHRCT-ND | Resistor
1 | 1 | 2 | ATMEGA2560-16AU | ATMEGA25602560-16AU | TQFP100 | IC3 | ATMEGA2560V-8AU-ND | http://www.digikey.com/product-search/en?keywords=ATMEGA2560V-8AU-ND | MICROCONTROLLER
1 | 1 | 2 | B82464G4 | B82464G4 | B82464G4 | U$7 | 495-1796-1-ND | http://www.digikey.com/product-search/en?keywords=495-1796-1-ND
2 | 1.5 | 6 | BAS16 | DIODESOD | SOD-323 | D1, D4 | BAS16HT1GCT-ND | http://www.digikey.com/product-search/en?keywords=BAS16HT1GCT-ND | Diode
1 | 1.5 | 3 | BZV5510V | BZV55 | MINIMELF | D9 | BZV55C10-TPMSCT-ND | http://www.digikey.com/product-search/en?keywords=BZV55C10-TPMSCT-ND
1 | 1.5 | 3 | BZV55C4.7V | BZV55 | MINIMELF | D10 | BZV55C4V7-TPMSCT-ND | http://www.digikey.com/product-search/en?keywords=BZV55C4V7-TPMSCT-ND
1 | 1.5 | 3 | CSTCE16M0V53-R0 16MHZ | RESONATORMU | RESONATOR | Y1 | 490-5994-1-ND | http://www.digikey.com/product-search/en?keywords=490-5994-1-ND
1 | 1.5 | 3 | FUSE | RESISTORPTH-1/4W-VERT | AXIAL-0.1 | R38 | F2438-ND | http://www.digikey.com/product-search/en?keywords=F2438-ND | Resistor
1 | 1 | 2 | LT365212 | LT365212 | 12-LEAD-MSOP-EXPOSED | U$5 | LT3652HVEMSE#PBF-ND | http://www.digikey.com/product-search/en?keywords=LT3652HVEMSE#PBF-ND | The LT®3652 is a complete monolithic step-down battery
1 | 1.5 | 3 | MBRS340 | MBRS340 | DO214BA | D8 | MBRS340T3GOSCT-ND | http://www.digikey.com/product-search/en?keywords=MBRS340T3GOSCT-ND
5 | 1.5 | 15 | MOSFET-PCHANNELSMD | MOSFET-PCHANNELSMD | SOT23-3 | Q2, Q3, Q4, Q8, Q9 | SSM3J328RLFCT-ND | http://www.digikey.com/product-search/en?keywords=SSM3J328RLFCT-ND | Generic PMOSFET
1 | 1 | 2 | MPU-9250 | MPU-9250 | QFN24_PAD | U1 | 1428-1019-1-ND | http://www.digikey.com/product-search/en?keywords=1428-1019-1-ND | NC pin 19. 2-6 & 14-17 not internally connected. May be used for PCB trace routing. IC-13192
1 | 10 | 20 | RED | LED-RED0603 | LED-0603 | STATUS | 475-2506-1-ND | http://www.digikey.com/product-search/en?keywords=475-2506-1-ND | Assorted Red LEDs DIO-00819 RED
1 | 1.5 | 3 | SI4401DDY | SI4401DDY | SOIC-8 | U$15 | SI4401DDY-T1-GE3CT-ND | http://www.digikey.com/product-search/en?keywords=SI4401DDY-T1-GE3CT-ND | VISHAY P-Channel 40 V (D-S) MOSFET
2 | 1.5 | 6 | SS1P3L | SS1P3L | MICROSMP | D$1, D$2 | MSS1P3L-M3/89AGICT-ND | http://www.digikey.com/product-search/en?keywords=MSS1P3L-M3/89AGICT-ND | Surface Mount Schottky Barrier Rectifiers
1 | 1 | 2 | TPS56X200 | TPS56X200 | SOT23-6 | U$2 | 296-37301-1-ND | http://www.digikey.com/product-search/en?keywords=296-37301-1-ND
1 | 1 | 2 | TPS62125 | TPS62125 | S-PWSON-N8 | U$1 | 296-30461-1-ND | http://www.digikey.com/product-search/en?keywords=296-30461-1-ND
1 | 1.5 | 3 |  | CAP_POL | DSK-621 | C30 | 604-1020-1-ND | http://www.digikey.com/product-search/en?keywords=604-1020-1-ND | Capacitor Polarized
1 | 1.5 | 3 | AVR_SPI_PRG_6PTH | AVR_SPI_PRG_6PTH | 2X3 | J1 |  |  | AVR ISP 6 Pin
1 | 1.5 | 3 | FTDI_DEVICE | FTDI_DEVICE | FTDI_DEVICE_SIDE | JP2 |  |  | Connector which mates to FTDI basic or FTDI cable.
2 | 1.5 | 6 | POWER_JACKPTH | POWER_JACKPTH | POWER_JACK_PTH | J2, J3 |  |  | Power Jack CONN-08197
1 | 1.5 | 3 | SMA_EDGE | SMA_EDGE | SMA-EDGE | JP5 |  |  | SMA Antenna Connector
1 | 1.5 | 3 | USD-SOCKETNEW | USD-SOCKETNEW | MICRO-SD-SOCKET-PP | U3 |  |  | microSD Socket
1 | 1.5 | 3 | VENUS638FLPX-L | VENUS638FLPX-L | VENUS638FLPX | U2 |  |  | Venus638FLPX-L GPS Receiver
1 | 1.5 | 3 |  | M01PTH | 1X01 | CHG |  |  | Header 1
2 | 1.5 | 6 |  | M03PTH | 1X03 | S_RUD, S_WINCH |  |  | Header 3
3 | 1.5 | 9 |  | M04PTH | 1X04 | AUX, CAM, WIND |  |  | Header 4 CONN-09696

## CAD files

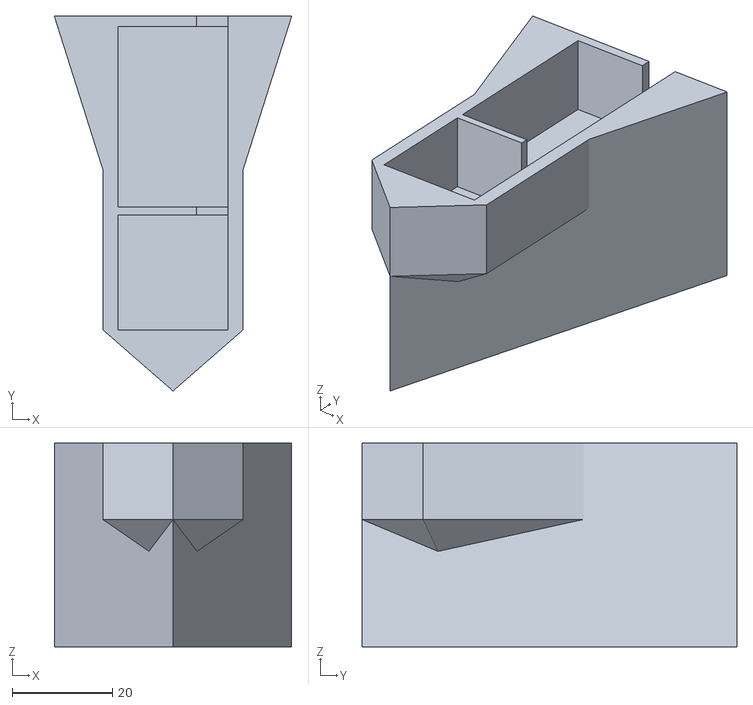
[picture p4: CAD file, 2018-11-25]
3dprint/compass mount.stl
47.3 x 74.7 x 40.6

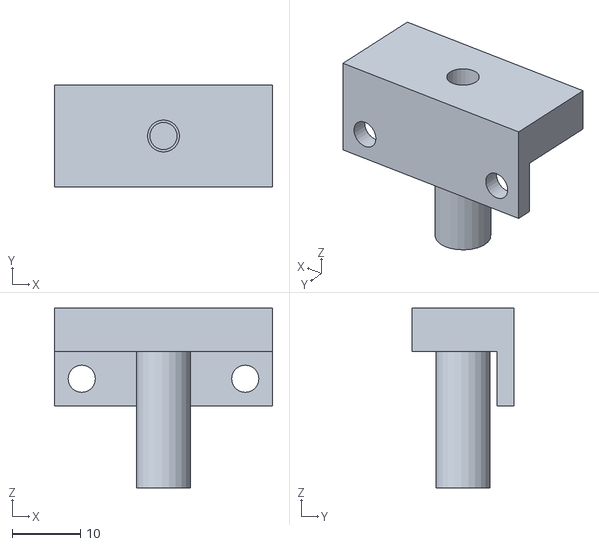
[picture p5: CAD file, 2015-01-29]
3dprint/enclosure/bracket.stl
32.0 x 15.0 x 26.3

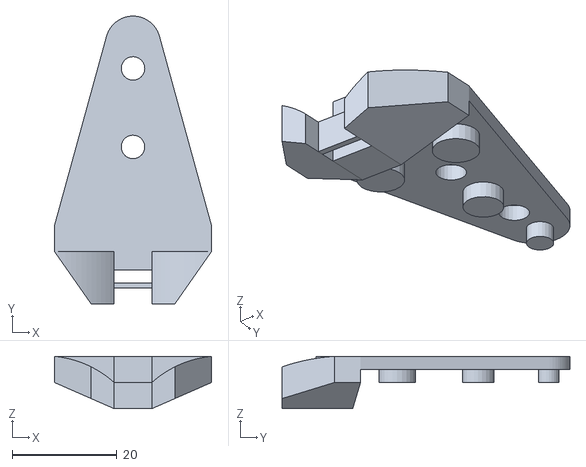
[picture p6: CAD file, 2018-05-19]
3dprint/outboard mount.stl
30.0 x 55.0 x 10.0

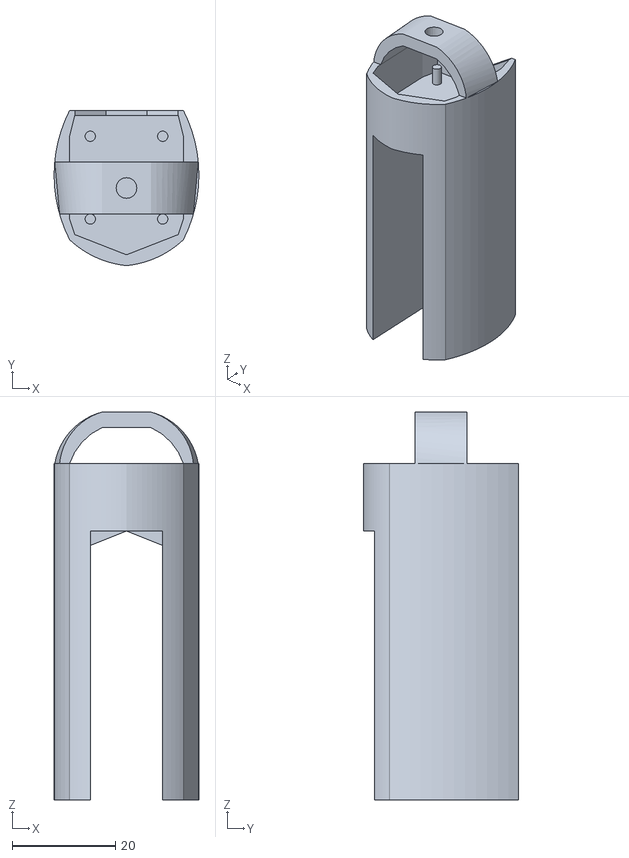
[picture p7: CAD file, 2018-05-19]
3dprint/vane 3.stl
28.0 x 30.0 x 75.0

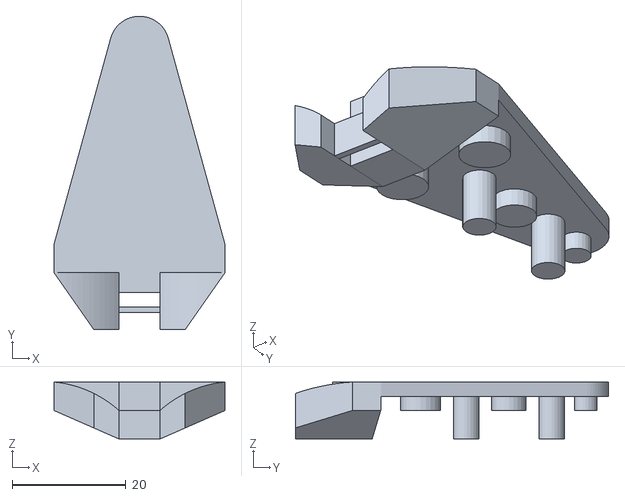
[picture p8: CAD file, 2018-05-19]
3dprint/outboard mount2.stl
30.0 x 55.0 x 10.0

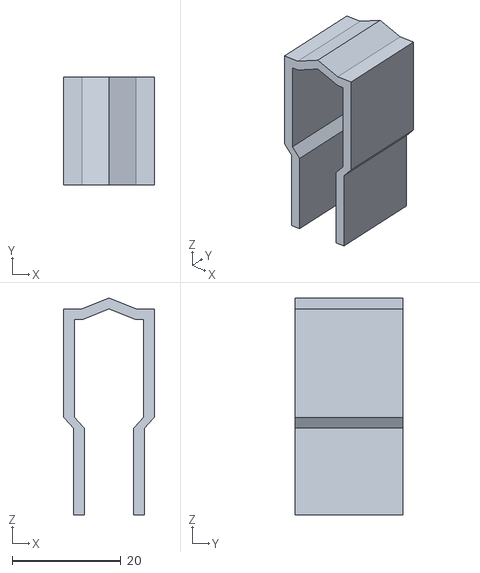
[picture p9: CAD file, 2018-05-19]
3dprint/vane mount.stl
16.7 x 20.0 x 40.0

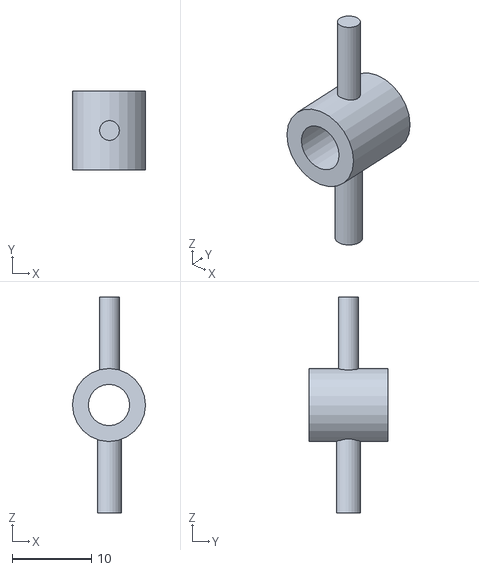
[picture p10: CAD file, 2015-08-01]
3dprint/vane 3 mag holder.stl
9.20 x 10.0 x 27.2

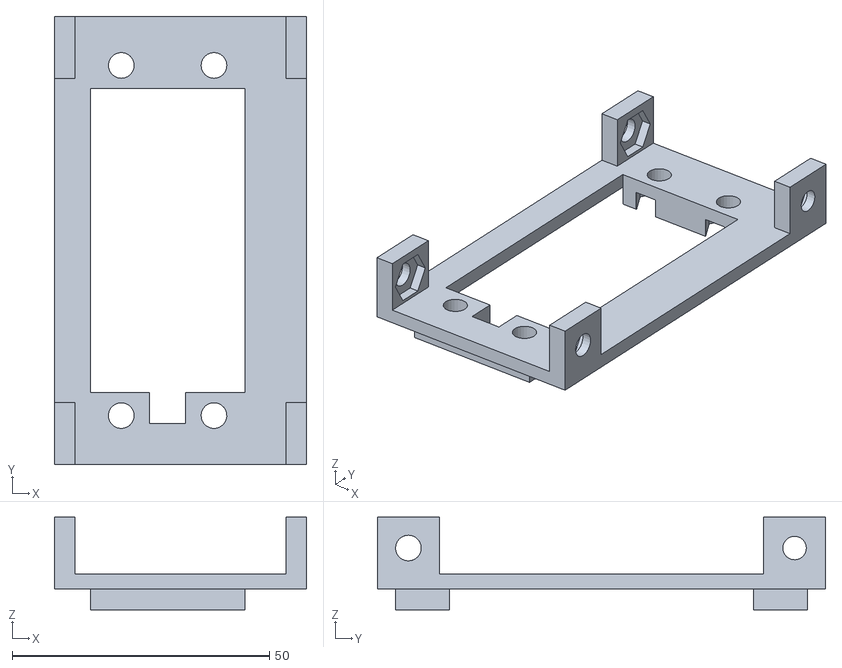
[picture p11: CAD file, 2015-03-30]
3dprint/winch enclosure top.v2.stl
49.0 x 87.0 x 18.0

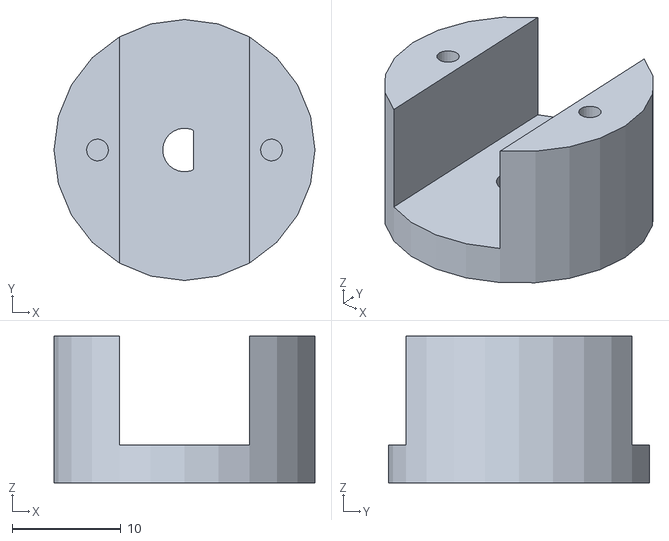
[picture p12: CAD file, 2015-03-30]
3dprint/servo shaft.v2.stl
24.0 x 24.0 x 13.5

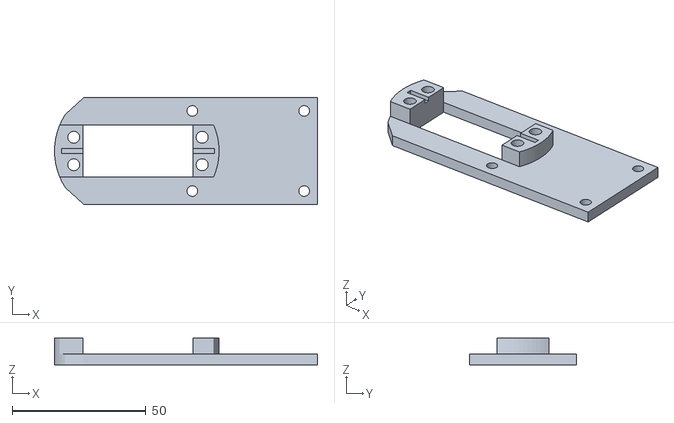
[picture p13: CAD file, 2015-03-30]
3dprint/rudder mount.v2.stl
98.5 x 40.0 x 10.0

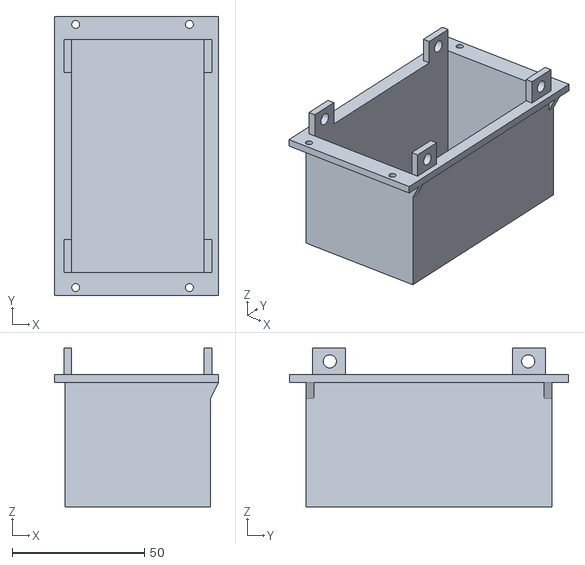
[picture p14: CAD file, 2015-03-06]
3dprint/winch enclosure bottom.stl
62.0 x 105.5 x 60.0

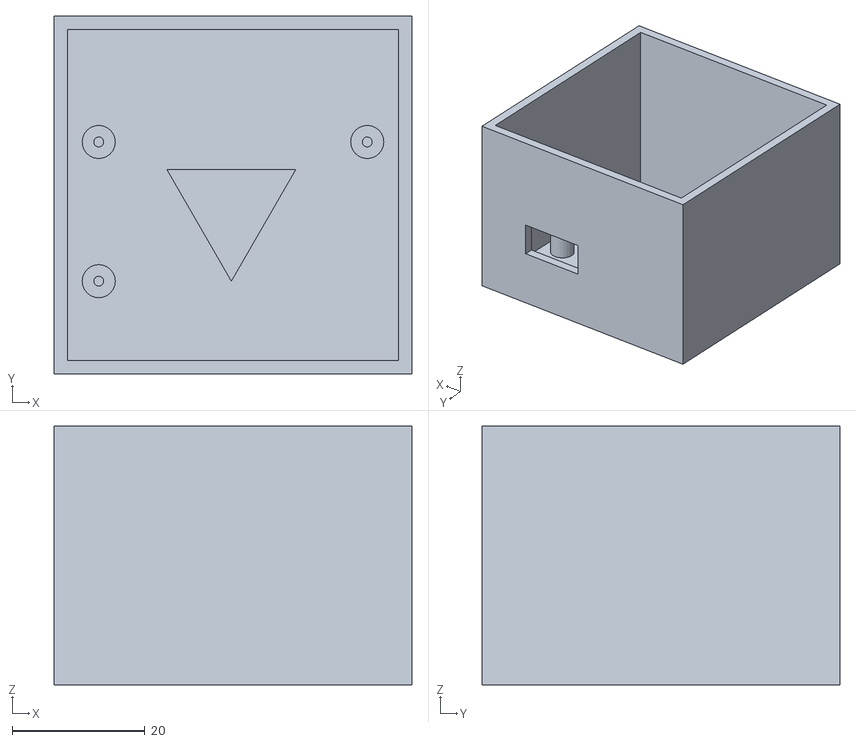
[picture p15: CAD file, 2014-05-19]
3dprint/camera housing.stl
54.0 x 54.0 x 39.0

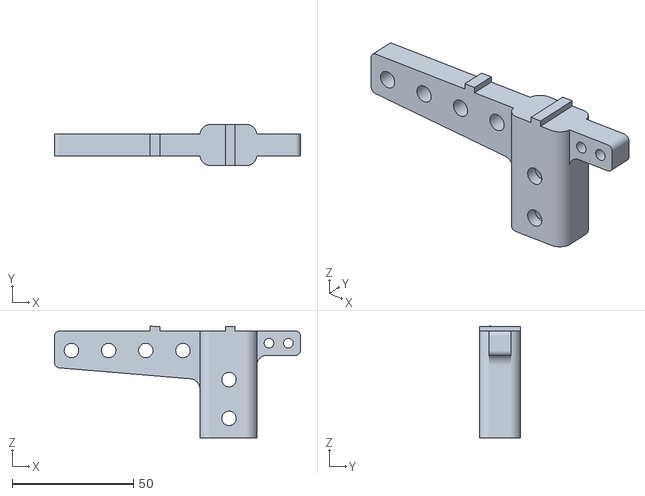
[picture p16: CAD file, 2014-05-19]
3dprint/crane.stl
101.5 x 17.0 x 46.0

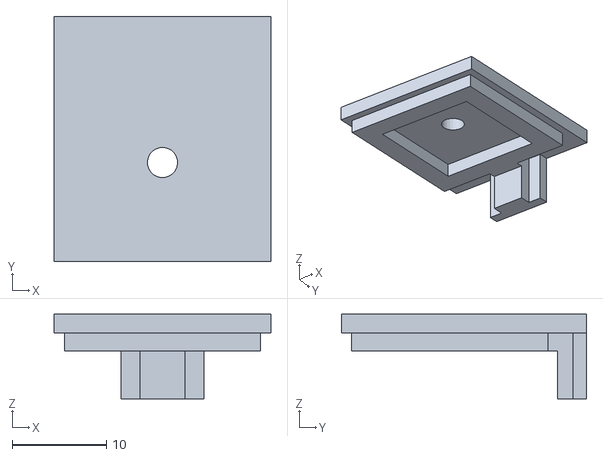
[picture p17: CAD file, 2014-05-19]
3dprint/vane housing_cover.stl
23.0 x 26.0 x 9.00

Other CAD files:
3dprint/vane housing_bottom.stl
3dprint/vane housing_flag.stl
3dprint/vane housing_shaft.stl
3dprint/rudder mount.stl
3dprint/camera housing.skp
3dprint/compass mount.skp
3dprint/compass mount~.skp
3dprint/crane.skp
3dprint/crane~.skp
3dprint/enclosure.skp
3dprint/enclosure/bracket.skp
3dprint/enclosure/bracket~.skp
3dprint/enclosure/enclosure master.skp
3dprint/enclosure/enclosure master~.skp
3dprint/enclosure~.skp
3dprint/outboard mount.skp
3dprint/outboard mount~.skp
3dprint/rudder arm.skp
3dprint/rudder arm~.skp
3dprint/rudder mount.skp
3dprint/rudder mount~.skp
3dprint/servo shaft.skp
3dprint/servo shaft.stl
3dprint/servo shaft~.skp
3dprint/vane 3.skp
3dprint/vane housing.skp
3dprint/vane housing2.skp
3dprint/vane housing2~.skp
3dprint/vane housing~.skp
3dprint/vane mount.skp
3dprint/vane mount~.skp
3dprint/winch enclosure top.stl
3dprint/winch enclosure.skp
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

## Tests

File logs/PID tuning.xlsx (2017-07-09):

lat | lon | gps age (ms) | gps speed (kt) | gps course | ahrs heading | roll | heel adjust | wind | wp heading | wp distance (m) | rudder (raw) | rudder (angle) | winch | voltage | cycle
41.923171 | -87.631523 | 571 | 0.9 | 194.8 | 157.96 | 10.85 | 0 | 7 | 151.95 | 63.68 | 110 | 20 | 56 | 11.38 | 2552
41.923171 | -87.631523 | 2374 | 0.9 | 194.8 | 162.9 | -32.03 | 4 | 70 | 120.46 | 36.9 | 50 | -40 | 84 | 11.38 | 2553
41.923168 | -87.631523 | 2173 | 0.8 | 196.9 | 154.59 | -20.69 | 0 | 152 | 119.68 | 36.52 | 125 | 35 | 120 | 11.39 | 2554
41.923168 | -87.631523 | 4590 | 0.8 | 196.9 | 143.63 | 0.53 | 0 | 328 | 119.68 | 36.52 | 125 | 35 | 71 | 11.38 | 2556
41.923164 | -87.63153 | 262 | 0 | 218.8 | 159.99 | -8.33 | 0 | 337 | 118.73 | 36.82 | 50 | -40 | 60 | 11.39 | 2560
41.923164 | -87.63153 | 531 | 0 | 218.8 | 157.85 | 1.64 | 0 | 335 | 118.73 | 36.82 | 59 | -31 | 60 | 11.38 | 2568
41.923164 | -87.63153 | 1235 | 0 | 218.8 | 158.62 | -1.15 | 0 | 331 | 118.73 | 36.82 | 121 | 31 | 60 | 11.38 | 2572
41.923164 | -87.63153 | 645 | 0 | 218.8 | 162.67 | -2.66 | 0 | 329 | 118.73 | 36.82 | 116 | 26 | 71 | 11.38 | 2575
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

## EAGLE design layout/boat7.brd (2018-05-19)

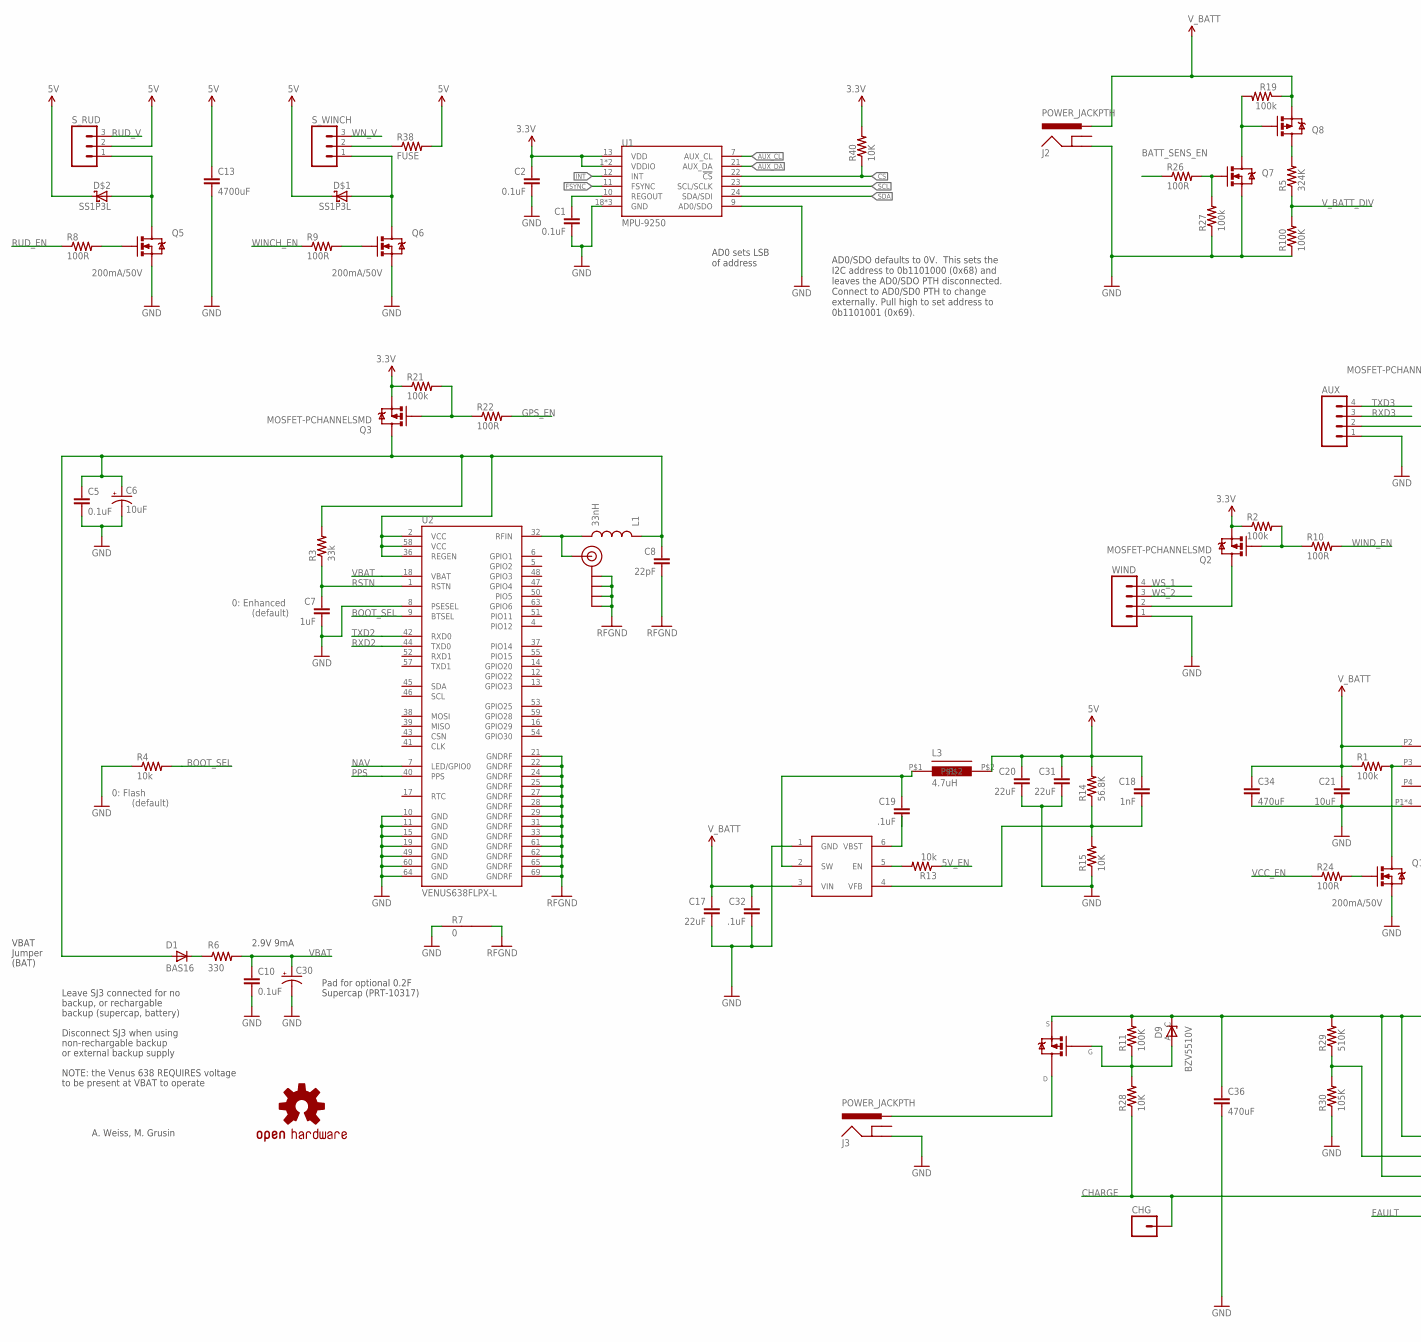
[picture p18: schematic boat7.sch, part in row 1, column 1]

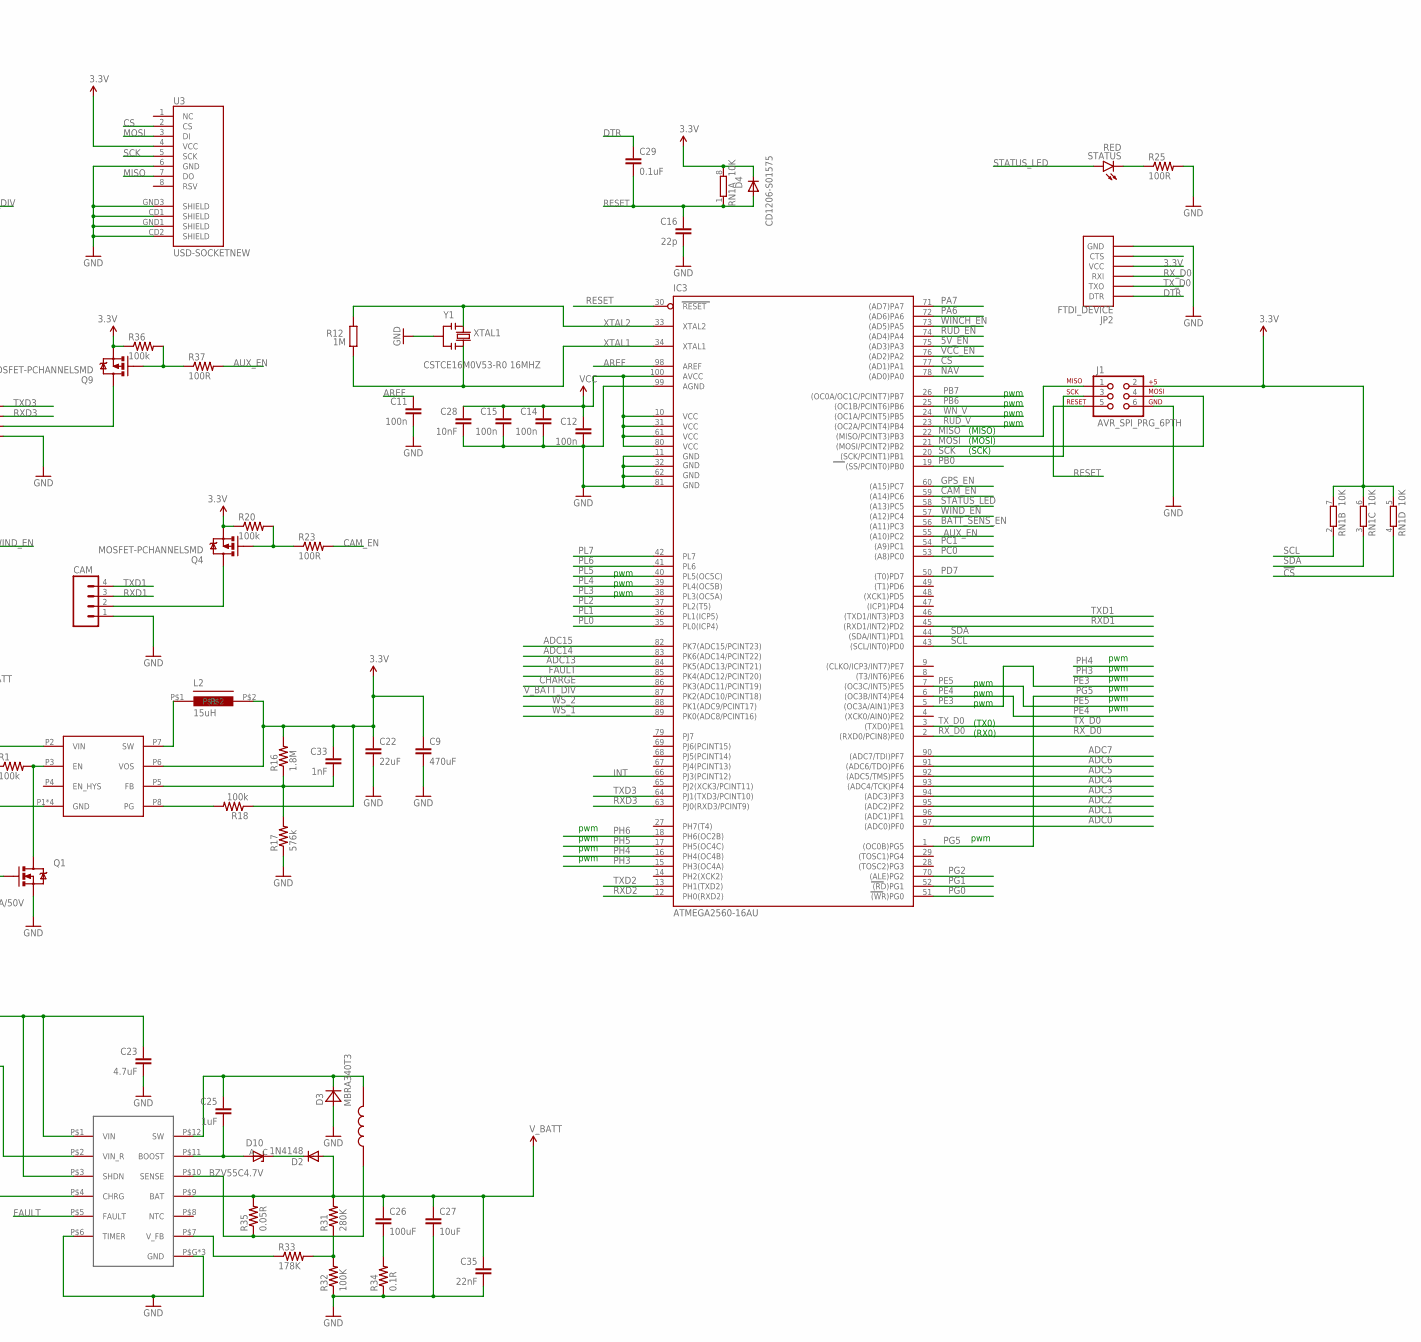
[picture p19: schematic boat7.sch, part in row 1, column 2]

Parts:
AUX: M04PTH; 1X04
C1, C2, C5, C10, C29: 0.1uF; 0603-CAP
C6: 10uF; EIA3216
C7: 1uF; 0603-CAP
C8: 22pF; 0603-CAP
C9, C34, C36: 470uF; CAP-PTH-5MM
C11, C12, C14, C15: 100n; C0603-ROUND
C13: 4700uF; CAP-PTH-5MM
C16: 22p; C0603-ROUND
C17, C20, C31: 22uF; 1206
C18: 1nF; 0805
C19, C32: .1uF; 0805
C21: 10uF; 0805
C22: 22uF; 0805
C23: 4.7uF; 1206
C25: 1uF; 0805
C26: 100uF; 1210
C27: 10uF; 1210
C28: 10nF; 0603-CAP
C30: CAP_POL; DSK-621
C33: 1nF; 0402-CAP
C35: 22nF; 0805
CAM: M04PTH; 1X04
CHG: M01PTH; 1X01
D1: BAS16; SOD-323
D2: 1N4148; MINIMELF
D3: MBRA340T3; SMA
D4: CD1206-S01575; SOD323-R
D9: BZV5510V; MINIMELF
D10: BZV55C4.7V; MINIMELF
D$1, D$2: SS1P3L; MICROSMP
IC3: ATMEGA2560-16AU; TQFP100
J1: AVR_SPI_PRG_6PTH; 2X3
J2, J3: POWER_JACKPTH; POWER_JACK_PTH
JP2: FTDI_DEVICE; FTDI_DEVICE_SIDE
JP5: SMA_EDGE; SMA-EDGE
L1: 33nH; 0603
L2: 15uH; VLCF4020
L3: 4.7uH; SLF7055
Q1, Q5, Q6, Q7: 200mA/50V; SOT23-3
Q2, Q3, Q4, Q8, Q9: MOSFET-PCHANNELSMD; SOT23-3
R1, R2, R18, R19, R20, R21, R27, R36: 100k; 0603-RES
R3: 33k; 0603-RES
R4, R13: 10k; 0603-RES
R5: 324K; 0603-RES
R6: 330; 0603-RES
R7: 0; GND-JUMP
R8, R9, R10, R22, R23, R24, R25, R26, R37: 100R; 0603-RES
R11, R32, R100: 100K; 0603-RES
R12: 1M; R0603-ROUND
R14: 56.8K; 0603-RES
R15, R28, R40: 10K; 0603-RES
R16: 1.8M; 0603-RES
R17: 576k; 0603-RES
R29: 510K; 0603-RES
R30: 105K; 0603-RES
R31: 280K; 0603-RES
R33: 178K; 0603-RES
R34: 0.1R; 1206
R35: 0.05R; 1206
R38: FUSE; AXIAL-0.1
RN1: 10K; CAT16
STATUS: RED; LED-0603
S_RUD: M03PTH; 1X03
S_WINCH: M03PTH; 1X03
U1: MPU-9250; QFN24_PAD
U2: VENUS638FLPX-L; VENUS638FLPX
U3: USD-SOCKETNEW; MICRO-SD-SOCKET-PP
U$1: TPS62125; S-PWSON-N8
U$2: TPS56X200; SOT23-6
U$4: OSHW-LOGOS; OSHW-LOGO-S
U$5: LT365212; 12-LEAD-MSOP-EXPOSED
U$7: B82464G4
U$15: SI4401DDY; SOIC-8
WIND: M04PTH; 1X04
Y1: CSTCE16M0V53-R0 16MHZ; RESONATOR

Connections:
3.3V: C2.1, C9.1, C12.1, C14.1, C15.1, C22.1, C28.1, C33.1, D4.C, IC3.10 (VCC), IC3.31 (VCC1), IC3.61 (VCC2), IC3.80 (VCC3), IC3.100 (AVCC), J1.2, JP2.P$4 (VCC), L2.P$2, Q2.2 (S), Q3.2 (S), Q4.2 (S), Q9.2 (S), R2.1, R16.2, R18.1, R20.1, R21.1, R36.1, R40.2, RN1.5 (2), RN1.6 (2), RN1.7 (2), RN1.8 (2), U1.1 (VDDIO), U1.8 (VDDIO), U1.13 (VDD), U3.4 (VCC), U$1.P6 (VOS)
5V: C13.1, C18.1, C20.1, C31.1, D$1.C, D$2.C, L3.P$2, R14.2, R38.P$2 (2), S_RUD.2
5V_EN: IC3.75 ((AD3)PA3), R13.1
!CS: R40.1, RN1.4 (1), U1.22 (!CS)
ADC0: IC3.97 ((ADC0)PF0)
ADC1: IC3.96 ((ADC1)PF1)
ADC2: IC3.95 ((ADC2)PF2)
ADC3: IC3.94 ((ADC3)PF3)
ADC4: IC3.93 ((ADC4/TCK)PF4)
ADC5: IC3.92 ((ADC5/TMS)PF5)
ADC6: IC3.91 ((ADC6/TDO)PF6)
ADC7: IC3.90 ((ADC7/TDI)PF7)
ADC13: IC3.84 (PK5(ADC13/PCINT21))
ADC14: IC3.83 (PK6(ADC14/PCINT22))
ADC15: IC3.82 (PK7(ADC15/PCINT23))
ANT: JP5.SIG (SIGNAL), L1.2, U2.32 (RFIN)
AREF: C11.1, IC3.98 (AREF)
AUX_CL: U1.7 (AUX_CL)
AUX_DA: U1.21 (AUX_DA)
AUX_EN: IC3.55 ((A10)PC2), R37.2
BAT: C17.1, C21.1, C26.1, C27.1, C32.1, C34.1, C35.1, D2.A, J2.PWR, Q8.2 (S), R1.1, R19.1, R31.2, R35.2, U$1.P2 (VIN), U$2.3 (VIN), U$5.P$9 (BAT)
BATT_SENS_EN: IC3.56 ((A11)PC3), R26.1
BOOST: C25.2, D10.A, U$5.P$11 (BOOST)
BOOT_SEL: R4.2, U2.9 (BTSEL)
CAM_EN: IC3.59 ((A14)PC6), R23.2
CHARGE: CHG.1, IC3.86 (PK3(ADC11/PCINT19)), R28.1, U$5.P$4 (CHRG)
CS: IC3.77 ((AD1)PA1), U3.2 (CS)
DTR: C29.1, JP2.P$1 (DTR)
FAULT: IC3.85 (PK4(ADC12/PCINT20)), U$5.P$5 (FAULT)
FSYNC: U1.11 (FSYNC)
GND: AUX.1, C1.2, C2.2, C5.2, C6.C (-), C7.2, C9.2, C10.2, C11.2, C12.2, C13.2, C14.2, C15.2, C16.2, C17.2, C20.2, C21.2, C22.2, C23.2, C27.2, C28.2, C30.GND (-), C31.2, C32.2, C34.2, C35.2, C36.2, CAM.1, D3.A, IC3.11 (GND), IC3.32 (GND1), IC3.62 (GND2), IC3.81 (GND3), IC3.99 (AGND), J1.6, J2.GND, J3.GND, JP2.P$6 (GND), Q1.2 (S), Q5.2 (S), Q6.2 (S), Q7.2 (S), R4.1, R7.1, R15.1, R17.1, R25.2, R27.1, R30.1, R32.1, R34.1, R100.1, U1.9 (AD0/SDO), U1.18 (GND), U1.20 (GND), U1.CENTER (GND), U2.8 (PSESEL), U2.10 (GND), U2.11 (GND), U2.15 (GND), U2.19 (GND), U2.49 (GND), U2.60 (GND), U2.64 (GND), U3.6 (GND), U3.CD1 (SHIELD), U3.CD2 (SHIELD), U3.GND1 (SHIELD), U3.GND3 (SHIELD), U$1.P1 (GND), U$1.P_THERM (GND), U$1.P_THERM_VIA (GND), U$1.P_THERM_VIA1 (GND), U$2.1 (GND), U$5.P$6 (TIMER), U$5.P$G (GND), U$5.P$G1 (GND), U$5.P$G2 (GND), WIND.1, Y1.2
GPS_EN: IC3.60 ((A15)PC7), R22.2
GPS_PWR: C5.1, C6.A (+), C8.1, D1.2 (A), L1.1, Q3.3 (D), R3.2, U2.2 (VCC), U2.36 (REGEN), U2.58 (VCC)
INT: IC3.66 (PJ3(PCINT12)), U1.12 (INT)
MISO: IC3.22 ((MISO/PCINT3)PB3), J1.1, U3.7 (DO)
MOSI: IC3.21 ((MOSI/PCINT2)PB2), J1.4, U3.3 (DI)
unnamed: R38.P$1 (1), S_WINCH.2
unnamed: AUX.2, Q9.3 (D)
unnamed: C23.1, C36.1, D9.C (K), R11.2, R29.2, U$5.P$1 (VIN), U$5.P$3 (SHDN), U$15.1 (S), U$15.2 (S), U$15.3 (S)
unnamed: D1.1 (C), R6.1
unnamed: D9.A, R11.1, R28.2, U$15.4 (G)
unnamed: Q5.1 (G), R8.2
unnamed: D$1.A, Q6.3 (D), S_WINCH.1
unnamed: D$2.A, Q5.3 (D), S_RUD.1
unnamed: Q6.1 (G), R9.2
unnamed: C19.1, L3.P$1, U$2.2 (SW)
unnamed: Q9.1 (G), R36.2, R37.1
unnamed: R31.1, R32.2, R33.2
unnamed: L2.P$1, U$1.P7 (SW)
unnamed: R13.2, U$2.5 (EN)
unnamed: C33.2, R16.1, R17.2, U$1.P5 (FB)
unnamed: R18.2, U$1.P8 (PG)
unnamed: C18.2, R14.1, R15.2, U$2.4 (VFB)
unnamed: CAM.2, Q4.3 (D)
unnamed: Q4.1 (G), R20.2, R23.1
unnamed: Q3.1 (G), R21.2, R22.1
unnamed: Q1.3 (D), R1.2, U$1.P3 (EN)
unnamed: Q1.1 (G), R24.2
unnamed: Q2.3 (D), WIND.2
unnamed: R25.1, STATUS.C
unnamed: Q2.1 (G), R2.2, R10.1
unnamed: Q8.3 (D), R5.2
unnamed: Q7.3 (D), Q8.1 (G), R19.2
unnamed: Q7.1 (G), R26.2, R27.2
unnamed: C19.2, U$2.6 (VBST)
unnamed: C26.2, R34.2
unnamed: D2.C, D10.C (K)
NAV: IC3.78 ((AD0)PA0), U2.7 (LED/GPIO0)
PA6: IC3.72 ((AD6)PA6)
PA7: IC3.71 ((AD7)PA7)
PB0: IC3.19 ((SS/PCINT0)PB0)
PB6: IC3.25 ((OC1B/PCINT6)PB6)
PB7: IC3.26 ((OC0A/OC1C/PCINT7)PB7)
PC0: IC3.53 ((A8)PC0)
PC1: IC3.54 ((A9)PC1)
PD7: IC3.50 ((T0)PD7)
PE3: IC3.5 ((OC3A/AIN1)PE3)
PE4: IC3.6 ((OC3B/INT4)PE4)
PE5: IC3.7 ((OC3C/INT5)PE5)
PG0: IC3.51 ((WR)PG0)
PG1: IC3.52 ((RD)PG1)
PG2: IC3.70 ((ALE)PG2)
PG5: IC3.1 ((OC0B)PG5)
PH3: IC3.15 (PH3(OC4A))
PH4: IC3.16 (PH4(OC4B))
PH5: IC3.17 (PH5(OC4C))
PH6: IC3.18 (PH6(OC2B))
PL0: IC3.35 (PL0(ICP4))
PL1: IC3.36 (PL1(ICP5))
PL2: IC3.37 (PL2(T5))
PL3: IC3.38 (PL3(OC5A))
PL4: IC3.39 (PL4(OC5B))
PL5: IC3.40 (PL5(OC5C))
PL6: IC3.41 (PL6)
PL7: IC3.42 (PL7)
PPS: U2.40 (PPS)
REGOUT: C1.1, U1.10 (REGOUT)
RESET: C16.1, C29.2, D4.A, IC3.30 (RESET), J1.5, RN1.1
RFGND: C8.2, JP5.GND@0 (GND), JP5.GND@1 (GND), JP5.GND@2 (GND), JP5.GND@3 (GND), R7.2, U2.21 (GNDRF), U2.22 (GNDRF), U2.24 (GNDRF), U2.25 (GNDRF), U2.27 (GNDRF), U2.28 (GNDRF), U2.29 (GNDRF), U2.31 (GNDRF), U2.33 (GNDRF), U2.61 (GNDRF), U2.62 (GNDRF), U2.65 (GNDRF), U2.69 (GNDRF)
RSTN: C7.1, R3.1, U2.1 (RSTN)
RUD_EN: IC3.74 ((AD4)PA4), R8.1
RUD_V: IC3.23 ((OC2A/PCINT4)PB4), S_RUD.3
RXD1: CAM.3, IC3.45 ((RXD1/INT2)PD2)
RXD2: IC3.12 (PH0(RXD2)), U2.44 (TXD0)
RXD3: AUX.3, IC3.63 (PJ0(RXD3/PCINT9))
RX_D0: IC3.2 ((RXD0/PCIN8)PE0), JP2.P$3 (RXI)
SCK: IC3.20 ((SCK/PCINT1)PB1), J1.3, U3.5 (SCK)
SCL: IC3.43 ((SCL/INT0)PD0), RN1.2 (1), U1.23 (SCL/SCLK)
SDA: IC3.44 ((SDA/INT1)PD1), RN1.3 (1), U1.24 (SDA/SDI)
SENSE: R35.1, U$5.P$10 (SENSE), U$7.P$1
STATUS_LED: IC3.58 ((A13)PC5), STATUS.A
SW: C25.1, D3.C, U$5.P$12 (SW), U$7.P$2
S_IN: J3.PWR, U$15.5 (D), U$15.6 (D), U$15.7 (D), U$15.8 (D)
TXD1: CAM.4, IC3.46 ((TXD1/INT3)PD3)
TXD2: IC3.13 (PH1(TXD2)), U2.42 (RXD0)
TXD3: AUX.4, IC3.64 (PJ1(TXD3/PCINT10))
TX_D0: IC3.3 ((TXD0)PE1), JP2.P$2 (TXO)
VBAT: C10.1, C30.VCC (+), R6.2, U2.18 (VBAT)
VCC_EN: IC3.76 ((AD2)PA2), R24.1
VFB: R33.1, U$5.P$7 (V_FB)
VINR: R29.1, R30.2, U$5.P$2 (VIN_R)
V_BATT_DIV: IC3.87 (PK2(ADC10/PCINT18)), R5.1, R100.2
WINCH_EN: IC3.73 ((AD5)PA5), R9.1
WIND_EN: IC3.57 ((A12)PC4), R10.2
WN_V: IC3.24 ((OC1A/PCINT5)PB5), S_WINCH.3
WS_1: IC3.89 (PK0(ADC8/PCINT16)), WIND.4
WS_2: IC3.88 (PK1(ADC9/PCINT17)), WIND.3
XTAL1: IC3.34 (XTAL1), R12.1, Y1.3
XTAL2: IC3.33 (XTAL2), R12.2, Y1.1

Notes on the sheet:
RFGND
0: Enhanced
0: Flash
(default)
A. Weiss, M. Grusin
Supercap (PRT-10317)
Pad for optional 0.2F
2.9V 9mA
VBAT
Jumper
(BAT)
Leave SJ3 connected for no
backup, or rechargable
backup (supercap, battery)
Disconnect SJ3 when using
non-rechargable backup
or external backup supply
NOTE: the Venus 638 REQUIRES voltage
to be present at VBAT to operate
pwm
(TX0)
(RX0)
(MISO)
(SCK)
(MOSI)
AD0/SDO defaults to 0V. This sets the I2C address to 0b1101000 (0x68) and leaves the AD0/SDO PTH disconnected. Connect to AD0/SD0 PTH to change externally. Pull high to set address to 0b1101001 (0x69).
AD0 sets LSB of address

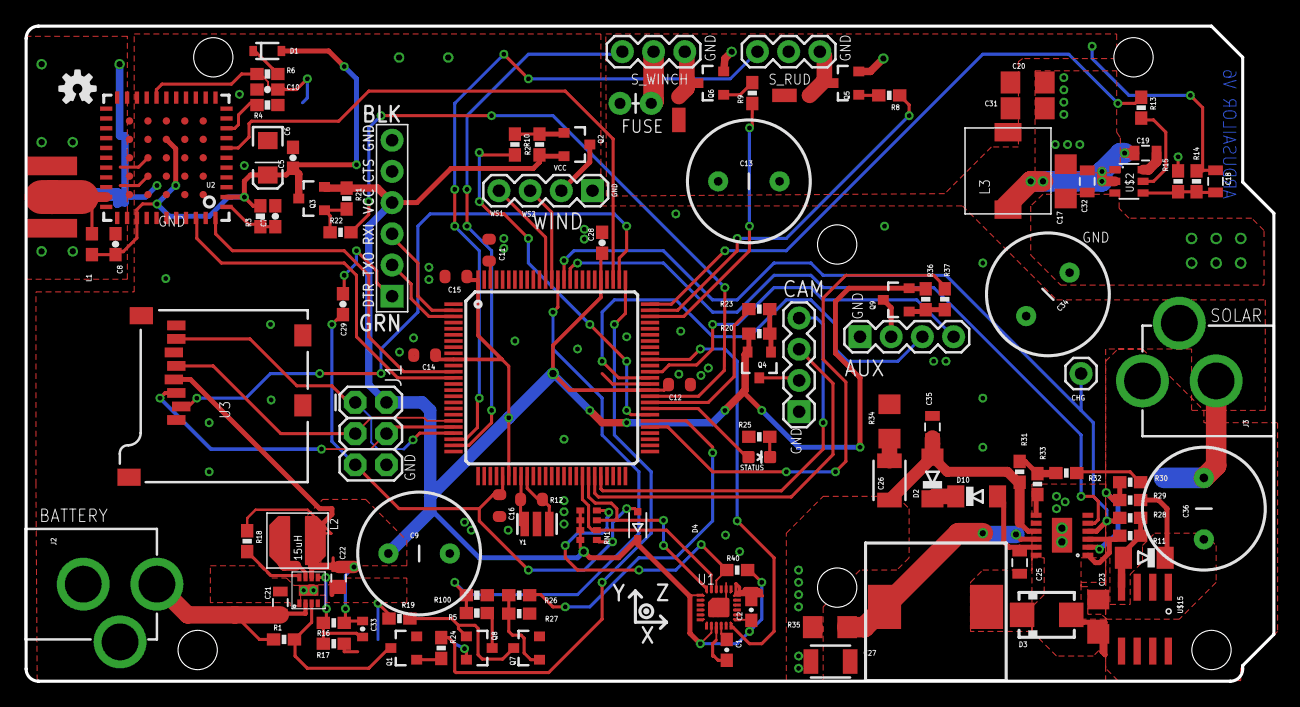
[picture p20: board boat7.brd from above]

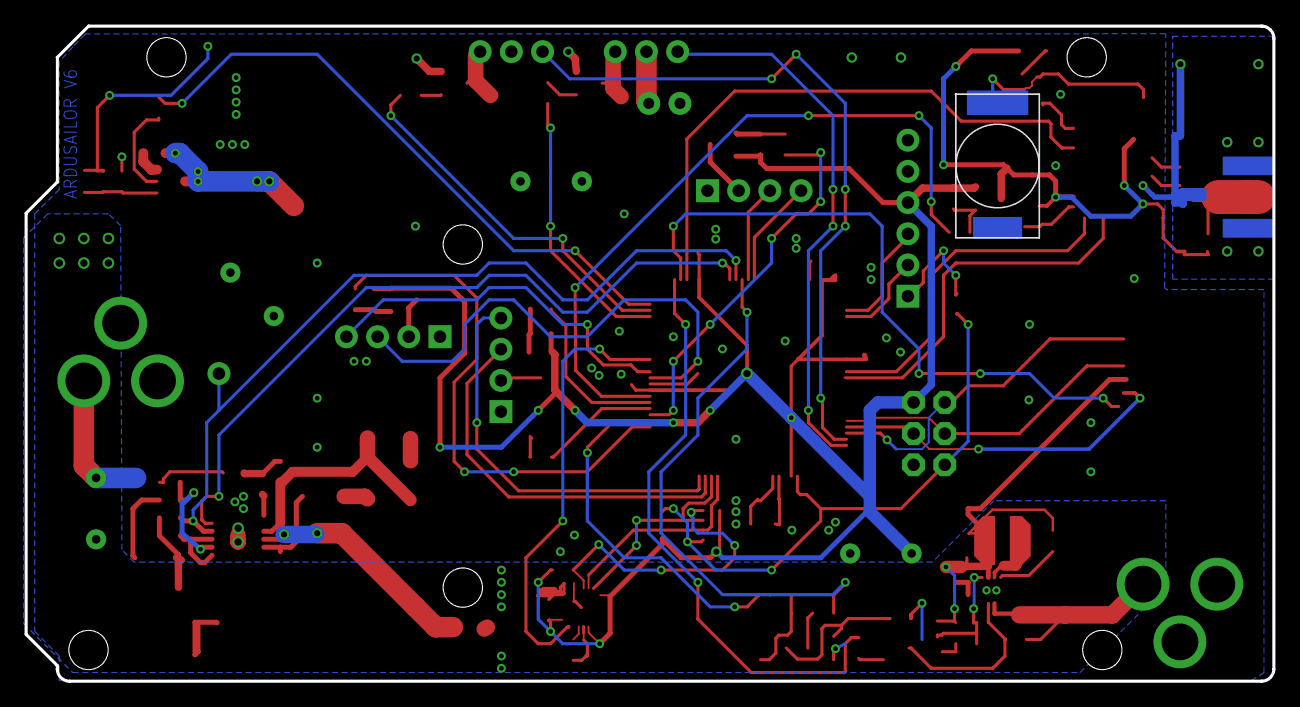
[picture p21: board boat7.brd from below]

Board: 2 copper layers, 101.6 x 53.3 mm, 117 parts (2 on the bottom side), 87 nets.

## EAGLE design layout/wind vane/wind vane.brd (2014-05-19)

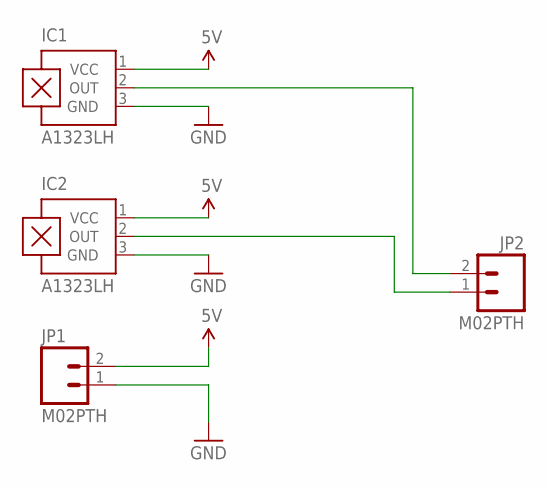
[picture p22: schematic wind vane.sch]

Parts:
IC1, IC2: A1323LH; SOT23-W
JP1, JP2: M02PTH; 1X02

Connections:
5V: IC1.1 (VCC), IC2.1 (VCC), JP1.2
GND: IC1.3 (GND), IC2.3 (GND), JP1.1
unnamed: IC1.2 (OUT), JP2.2
unnamed: IC2.2 (OUT), JP2.1

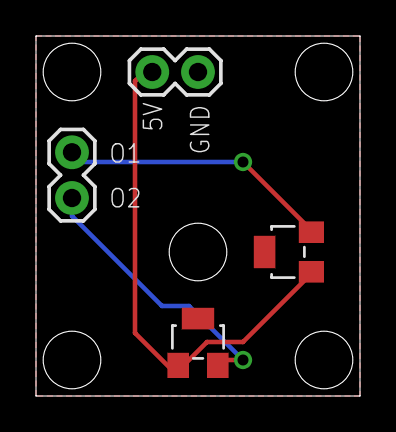
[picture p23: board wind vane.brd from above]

Board: 2 copper layers, 18.0 x 20.0 mm, 4 parts (0 on the bottom side), 4 nets.

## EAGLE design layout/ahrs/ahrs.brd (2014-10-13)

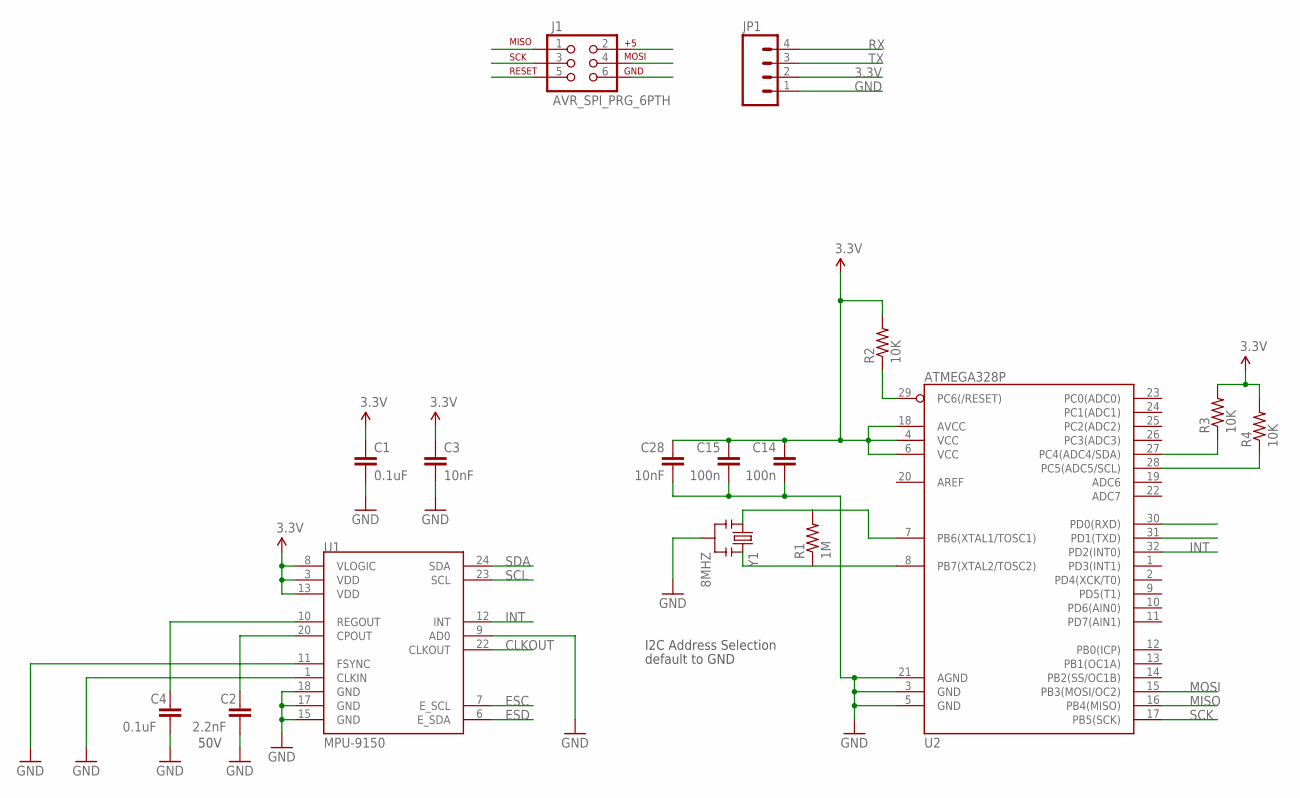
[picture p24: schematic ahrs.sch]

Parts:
C1, C4: 0.1uF; 0603-CAP
C2: 2.2nF; 0603-CAP
C3, C28: 10nF; 0603-CAP
C14, C15: 100n; C0603-ROUND
J1: AVR_SPI_PRG_6PTH; 2X3
JP1: M04PTH; 1X04
R1: 1M; 0603-RES
R2, R3, R4: 10K; 0603-RES
U1: MPU-9150; QFN-24-NP
U2: ATMEGA328P; TQFP32-08
Y1: 8MHZ; RESONATOR-SMD

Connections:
3.3V: C1.1, C3.1, C14.1, C15.1, C28.1, J1.2, JP1.2, R2.2, R3.2, R4.2, U1.3 (VDD), U1.8 (VLOGIC), U1.13 (VDD), U2.4 (VCC), U2.6 (VCC), U2.18 (AVCC)
CLKOUT: U1.22 (CLKOUT)
ESC: U1.7 (E_SCL)
ESD: U1.6 (E_SDA)
GND: C1.2, C2.2, C3.2, C4.2, C14.2, C15.2, C28.2, J1.6, JP1.1, U1.1 (CLKIN), U1.9 (AD0), U1.11 (FSYNC), U1.15 (GND), U1.17 (GND), U1.18 (GND), U2.3 (GND), U2.5 (GND), U2.21 (AGND), Y1.2
INT: U1.12 (INT), U2.32 (PD2(INT0))
MISO: J1.1, U2.16 (PB4(MISO))
MOSI: J1.4, U2.15 (PB3(MOSI/OC2))
unnamed: C2.1, U1.20 (CPOUT)
unnamed: C4.1, U1.10 (REGOUT)
unnamed: R1.2, U2.7 (PB6(XTAL1/TOSC1)), Y1.1
unnamed: R1.1, U2.8 (PB7(XTAL2/TOSC2)), Y1.3
RESET: J1.5, R2.1, U2.29 (PC6(/RESET))
RX: JP1.4, U2.30 (PD0(RXD))
SCK: J1.3, U2.17 (PB5(SCK))
SCL: R4.1, U1.23 (SCL), U2.28 (PC5(ADC5/SCL))
SDA: R3.1, U1.24 (SDA), U2.27 (PC4(ADC4/SDA))
TX: JP1.3, U2.31 (PD1(TXD))

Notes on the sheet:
50V
I2C Address Selection
default to GND

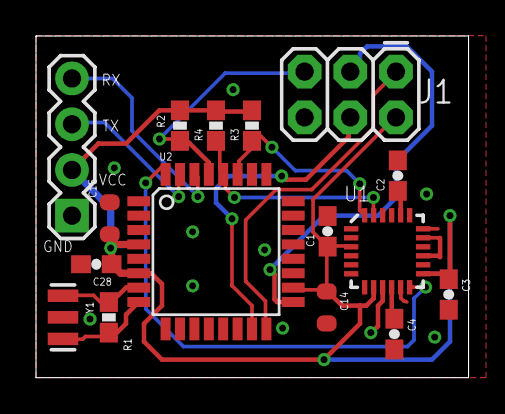
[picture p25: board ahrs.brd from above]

Board: 2 copper layers, 24.0 x 19.0 mm, 16 parts (0 on the bottom side), 15 nets.

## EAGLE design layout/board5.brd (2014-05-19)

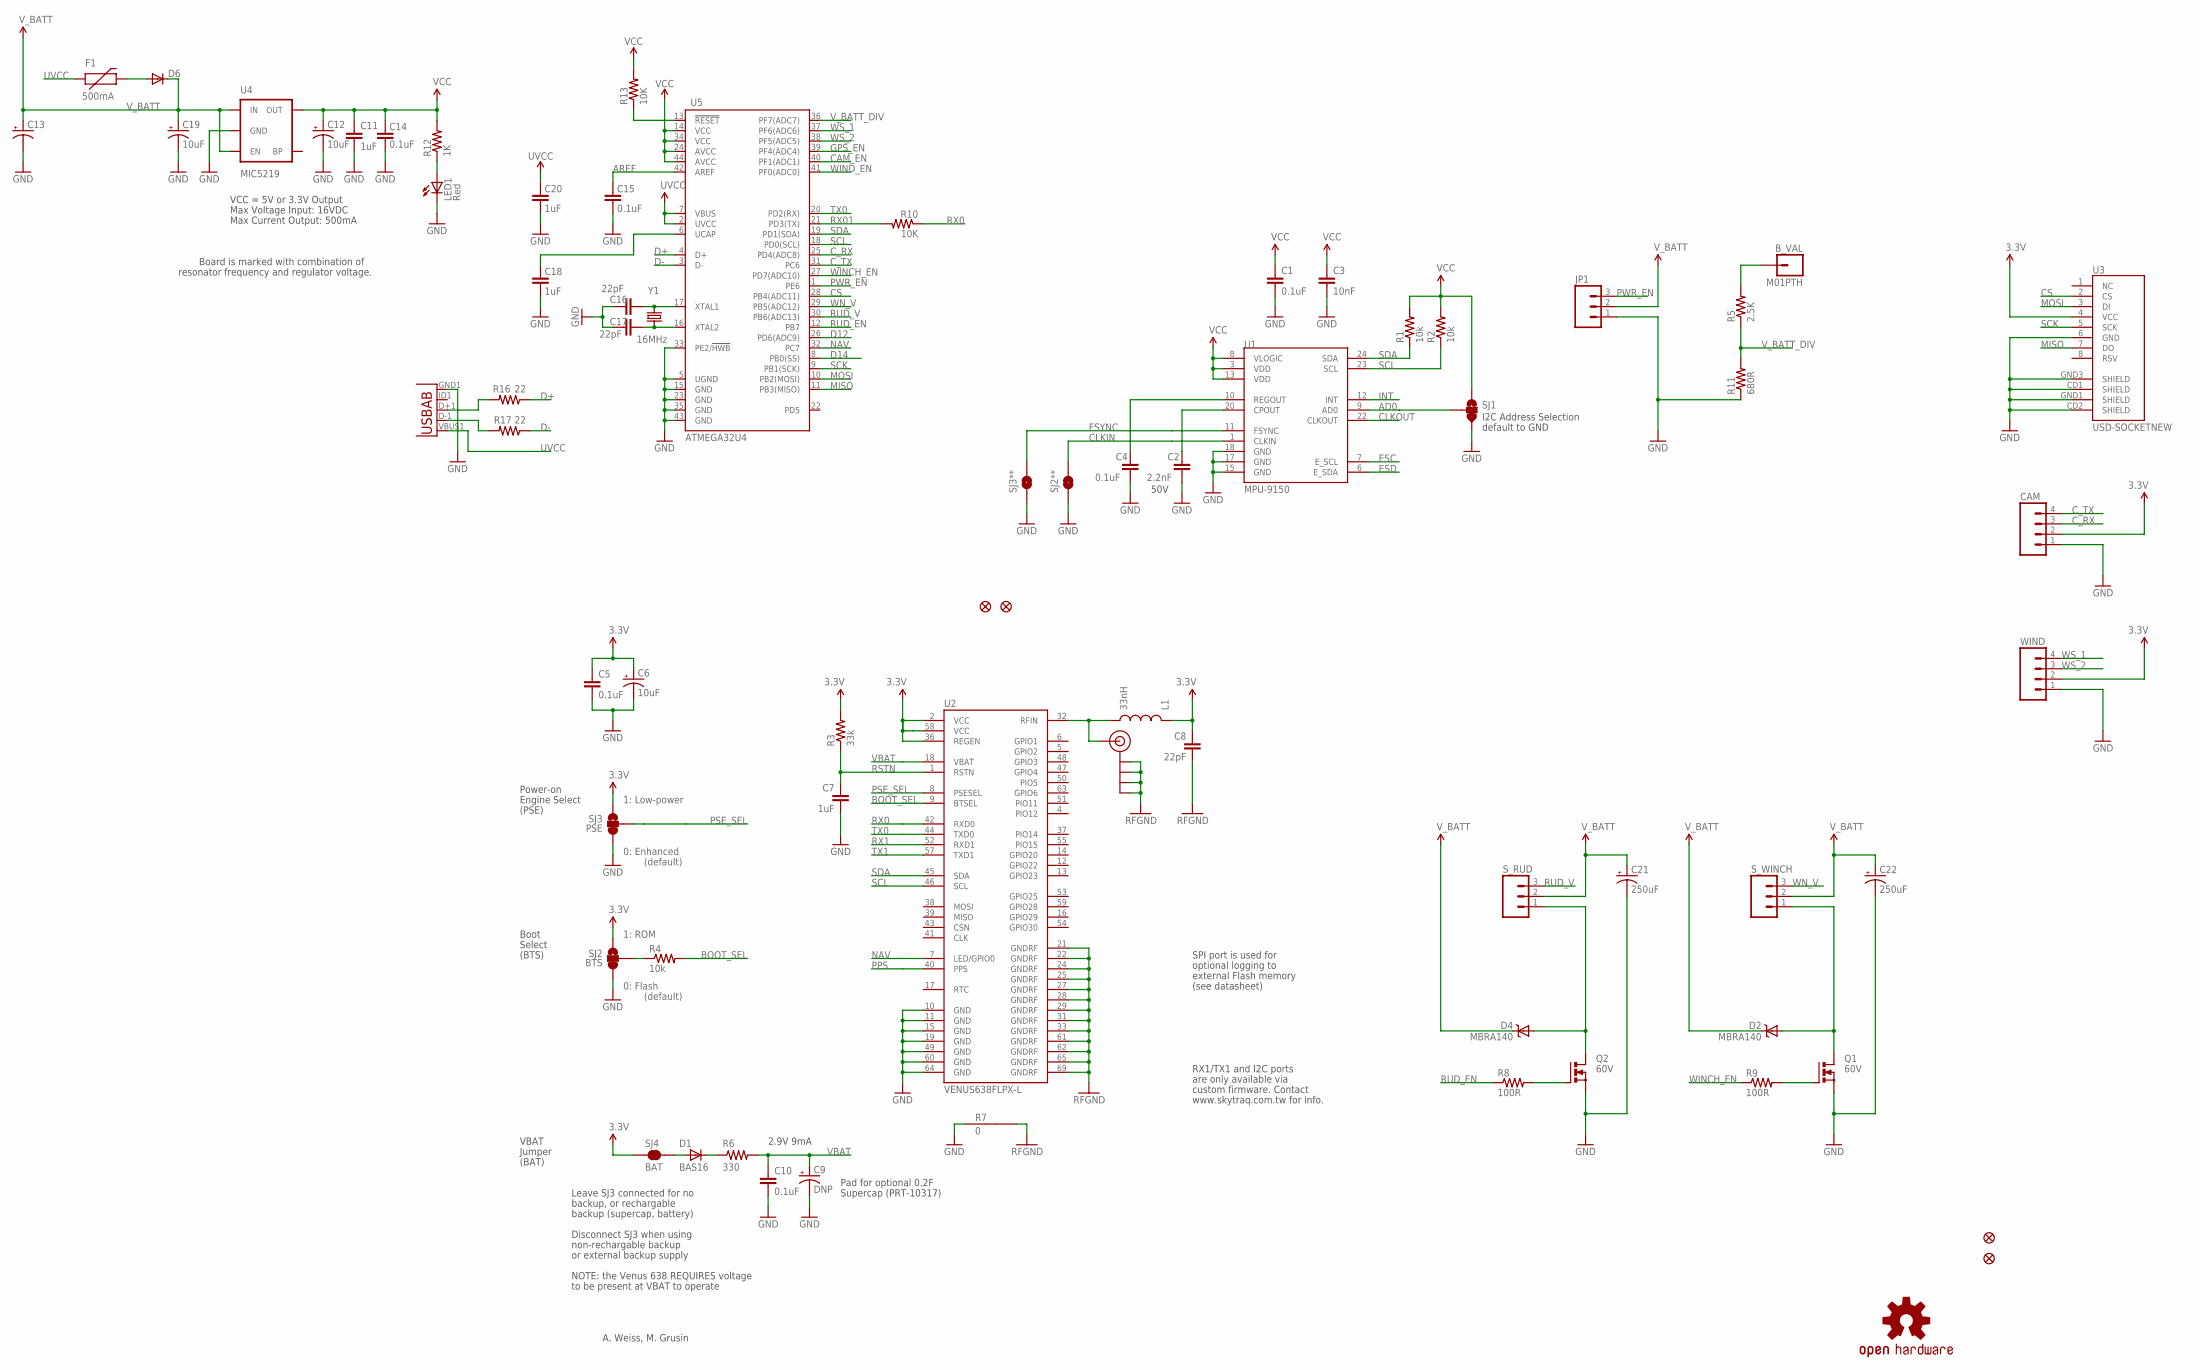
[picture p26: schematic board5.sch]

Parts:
B_VAL: M01PTH; 1X01
C1, C4, C5, C10: 0.1uF; 0402-CAP
C2: 2.2nF; 0402-CAP
C3: 10nF; 0402-CAP
C6, C12, C19: 10uF; EIA3216
C7: 1uF; 0402-CAP
C8: 22pF; 0402-CAP
C9: DNP; CPOL-RADIAL-1000UF-25V
C11, C18, C20: 1uF; 0603-CAP
C13: CAP_POLPTH4; CPOL-RADIAL-1000UF-25V
C14, C15: 0.1uF; 0603-CAP
C16, C17: 22pF; 0603-CAP
C21, C22: 250uF; CPOL-RADIAL-1000UF-25V
CAM: M04PTH; 1X04
D1: BAS16; SOD-323
D2, D4: MBRA140; SMA-DIODE
D6: DIODESOD; SOD-323
F1: 500mA; PTC-1206
JP1: M03SCREW; SCREWTERMINAL-3.5MM-3
JP3, JP4, JP7, JP8: FIDUCIALUFIDUCIAL; MICRO-FIDUCIAL
JP5: SMA_EDGE; SMA-EDGE
L1: 33nH; C0402
LED1: Red; LED-0603
Q1, Q2: 60V; TO220BV
R1, R2: 10k; 0603-RES
R3: 33k; 0402-RES
R4: 10k; 0402-RES
R5: 2.5K; 0603-RES
R6: 330; 0402-RES
R7: 0; GND-JUMP
R8, R9: 100R; 0603-RES
R10: 10K; 0402-RES
R11: 680R; 0603-RES
R12: 1K; 0603-RES
R13: 10K; 0603-RES
R16, R17: 22; 0603-RES
SJ1: SOLDERJUMPER_2WAYPASTE2&3; SJ_3_PASTE2&3
SJ2: BTS; SJ_3_PASTE2&3
SJ2**, SJ3**: SOLDERJUMPERTRACE; SJ_2S-TRACE
SJ3: PSE; SJ_3_PASTE2&3
SJ4: BAT; SJ_2S
S_RUD: M03PTH; 1X03
S_WINCH: M03PTH; 1X03
U1: MPU-9150; QFN-24-NP
U2: VENUS638FLPX-L; VENUS638FLPX
U3: USD-SOCKETNEW; MICRO-SD-SOCKET-PP
U4: MIC5219; SOT23-5
U5: ATMEGA32U4; QFN-44-NOPAD_1:1-OUTFAKES
U$4: OSHW-LOGOS; OSHW-LOGO-S
WIND: M04PTH; 1X04
X1: USB-ABIN&OUT; USB-AB-MICRO-SMD-V03-IN&OUT
Y1: 16MHz; CRYSTAL-SMD-5X3

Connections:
3.3V: C1.1, C3.1, C11.1, C12.A (+), C14.2, R1.2, R2.2, R12.2, R13.2, SJ1.1, U1.3 (VDD), U1.8 (VLOGIC), U1.13 (VDD), U3.4 (VCC), U4.5 (OUT), U5.14 (VCC), U5.24 (AVCC), U5.34 (VCC), U5.44 (AVCC)
AD0: SJ1.2, U1.9 (AD0)
ANT: JP5.SIG (SIGNAL), L1.2, U2.32 (RFIN)
AREF: C15.2, U5.42 (AREF)
BOOT_SEL: R4.2, U2.9 (BTSEL)
CAM_EN: CAM.2, U5.40 (PF1(ADC1))
CLKIN: SJ2**.2, U1.1 (CLKIN)
CLKOUT: U1.22 (CLKOUT)
CS: U3.2 (CS), U5.28 (PB4(ADC11))
C_RX: CAM.3, U5.25 (PD4(ADC8))
C_TX: CAM.4, U5.31 (PC6)
D12: U5.26 (PD6(ADC9))
D14: U5.8 (PB0(SS))
D+: R16.1, U5.4 (D+)
D-: R17.1, U5.3 (D-)
ESC: U1.7 (E_SCL)
ESD: U1.6 (E_SDA)
FSYNC: SJ3**.2, U1.11 (FSYNC)
GND: C1.2, C2.2, C3.2, C4.2, C5.2, C6.C (-), C7.2, C9.2 (-), C10.2, C11.2, C12.C (-), C13.2 (-), C14.1, C15.1, C16.2, C17.2, C18.1, C19.C (-), C20.1, C21.2 (-), C22.2 (-), CAM.1, JP1.1, LED1.C, Q1.S, Q2.S, R7.1, R11.1, SJ1.3, SJ2.3, SJ2**.1, SJ3.3, SJ3**.1, U1.15 (GND), U1.17 (GND), U1.18 (GND), U2.10 (GND), U2.11 (GND), U2.15 (GND), U2.19 (GND), U2.49 (GND), U2.60 (GND), U2.64 (GND), U3.6 (GND), U3.CD1 (SHIELD), U3.CD2 (SHIELD), U3.GND1 (SHIELD), U3.GND3 (SHIELD), U4.2 (GND), U5.5 (UGND), U5.15 (GND), U5.23 (GND), U5.33 (PE2/!HWB), U5.35 (GND), U5.43 (GND), WIND.1, X1.GND1 (GND)
GPS_EN: C5.1, C6.A (+), C8.1, L1.1, R3.2, SJ2.1, SJ3.1, SJ4.1, U2.2 (VCC), U2.36 (REGEN), U2.58 (VCC), U5.39 (PF4(ADC4))
INT: U1.12 (INT)
MISO: U3.7 (DO), U5.11 (PB3(MISO))
MOSI: U3.3 (DI), U5.10 (PB2(MOSI))
unnamed: C2.1, U1.20 (CPOUT)
unnamed: C4.1, U1.10 (REGOUT)
unnamed: B_VAL.1, R5.2
unnamed: R4.1, SJ2.2
unnamed: D1.1 (C), R6.1
unnamed: D1.2 (A), SJ4.2
unnamed: Q2.G, R8.2
unnamed: D2.A, Q1.D, S_WINCH.1
unnamed: D4.A, Q2.D, S_RUD.1
unnamed: Q1.G, R9.2
unnamed: C17.1, U5.16 (XTAL2), Y1.1
unnamed: C16.1, U5.17 (XTAL1), Y1.3 (2)
unnamed: C18.2, U5.6 (UCAP)
unnamed: R17.2, X1.D-1 (D-)
unnamed: R16.2, X1.D+1 (D+)
unnamed: D6.2 (A), F1.2
unnamed: LED1.A, R12.1
NAV: U2.7 (LED/GPIO0), U5.32 (PC7)
PPS: U2.40 (PPS)
PSE_SEL: SJ3.2, U2.8 (PSESEL)
PWR_EN: JP1.3, U5.1 (PE6)
RESET: R13.1, U5.13 (!RESET)
RFGND: C8.2, JP5.GND@0 (GND), JP5.GND@1 (GND), JP5.GND@2 (GND), JP5.GND@3 (GND), R7.2, U2.21 (GNDRF), U2.22 (GNDRF), U2.24 (GNDRF), U2.25 (GNDRF), U2.27 (GNDRF), U2.28 (GNDRF), U2.29 (GNDRF), U2.31 (GNDRF), U2.33 (GNDRF), U2.61 (GNDRF), U2.62 (GNDRF), U2.65 (GNDRF), U2.69 (GNDRF)
RSTN: C7.1, R3.1, U2.1 (RSTN)
RUD_EN: R8.1, U5.12 (PB7)
RUD_V: S_RUD.3, U5.30 (PB6(ADC13))
RX0: R10.1, U2.42 (RXD0)
RX1: U2.52 (RXD1)
RX01: R10.2, U5.21 (PD3(TX))
SCK: U3.5 (SCK), U5.9 (PB1(SCK))
SCL: R2.1, U1.23 (SCL), U2.46 (SCL), U5.18 (PD0(SCL))
SDA: R1.1, U1.24 (SDA), U2.45 (SDA), U5.19 (PD1(SDA))
TX0: U2.44 (TXD0), U5.20 (PD2(RX))
TX1: U2.57 (TXD1)
UVCC: C20.2, F1.1, U5.2 (UVCC), U5.7 (VBUS), X1.VBUS1 (VBUS)
VBAT: C9.1 (+), C10.1, R6.2, U2.18 (VBAT)
V_BATT: C13.1 (+), C19.A (+), C21.1 (+), C22.1 (+), D2.C, D4.C, D6.1 (C), JP1.2, S_RUD.2, S_WINCH.2, U4.1 (IN), U4.3 (EN)
V_BATT_DIV: R5.1, R11.2, U5.36 (PF7(ADC7))
WINCH_EN: R9.1, U5.27 (PD7(ADC10))
WIND_EN: U5.41 (PF0(ADC0)), WIND.2
WN_V: S_WINCH.3, U5.29 (PB5(ADC12))
WS_1: U5.37 (PF6(ADC6)), WIND.4
WS_2: U5.38 (PF5(ADC5)), WIND.3

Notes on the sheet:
50V
I2C Address Selection
default to GND
RFGND
1: Low-power
0: Enhanced
0: Flash
1: ROM
(default)
A. Weiss, M. Grusin
Supercap (PRT-10317)
Pad for optional 0.2F
2.9V 9mA
RX1/TX1 and I2C ports
are only available via
SPI port is used for
optional logging to
external Flash memory
(see datasheet)
custom firmware. Contact
www.skytraq.com.tw for info.
Power-on
Engine Select
Boot
Select
(PSE)
(BTS)
VBAT
Jumper
(BAT)
Leave SJ3 connected for no
backup, or rechargable
backup (supercap, battery)
Disconnect SJ3 when using
non-rechargable backup
or external backup supply
NOTE: the Venus 638 REQUIRES voltage
to be present at VBAT to operate
Max Voltage Input: 16VDC
Max Current Output: 500mA

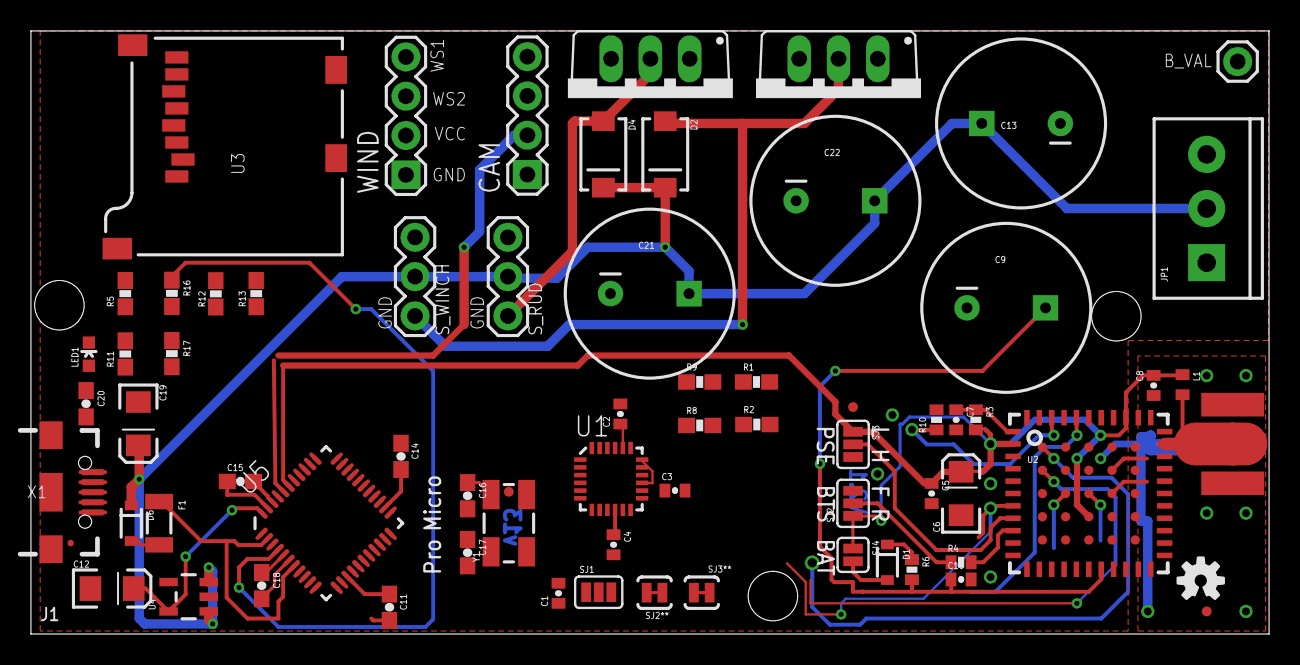
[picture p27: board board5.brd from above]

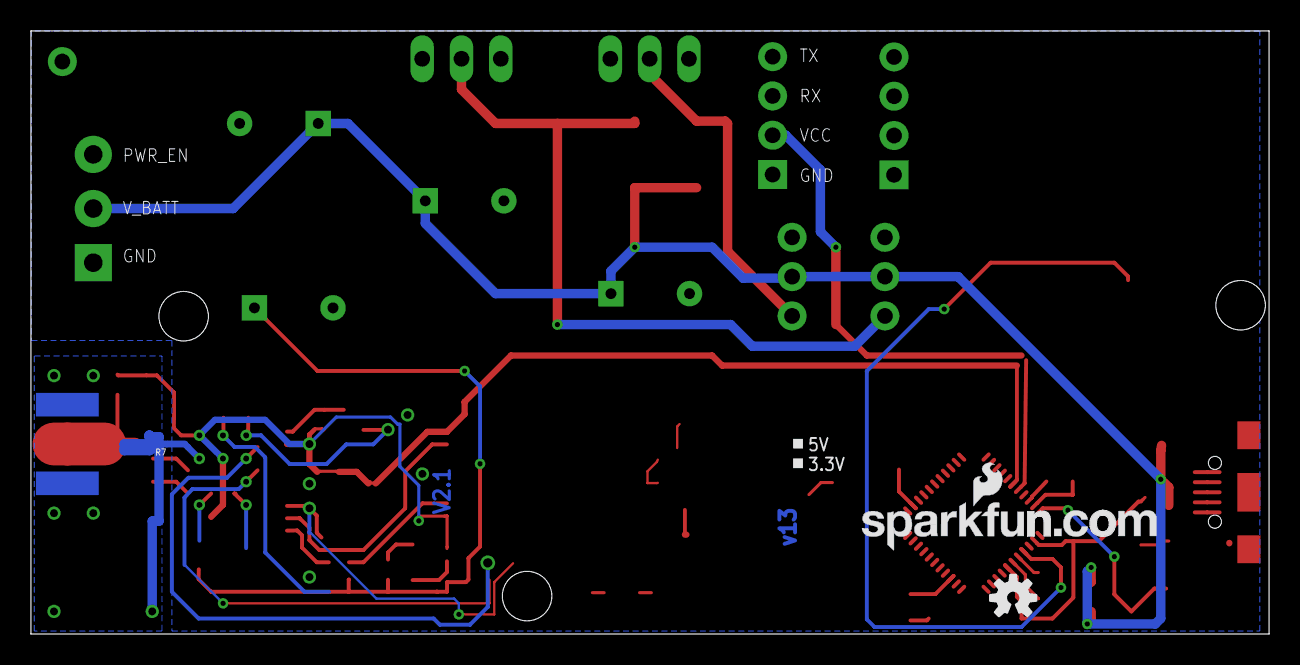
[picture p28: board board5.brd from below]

Board: 2 copper layers, 80.0 x 39.0 mm, 73 parts (3 on the bottom side), 57 nets.

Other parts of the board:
U$3: OSHW-LOGOS; OSHW-LOGO-S
U$11: LOGO-SFENEW; SFE-NEW-WEBLOGO

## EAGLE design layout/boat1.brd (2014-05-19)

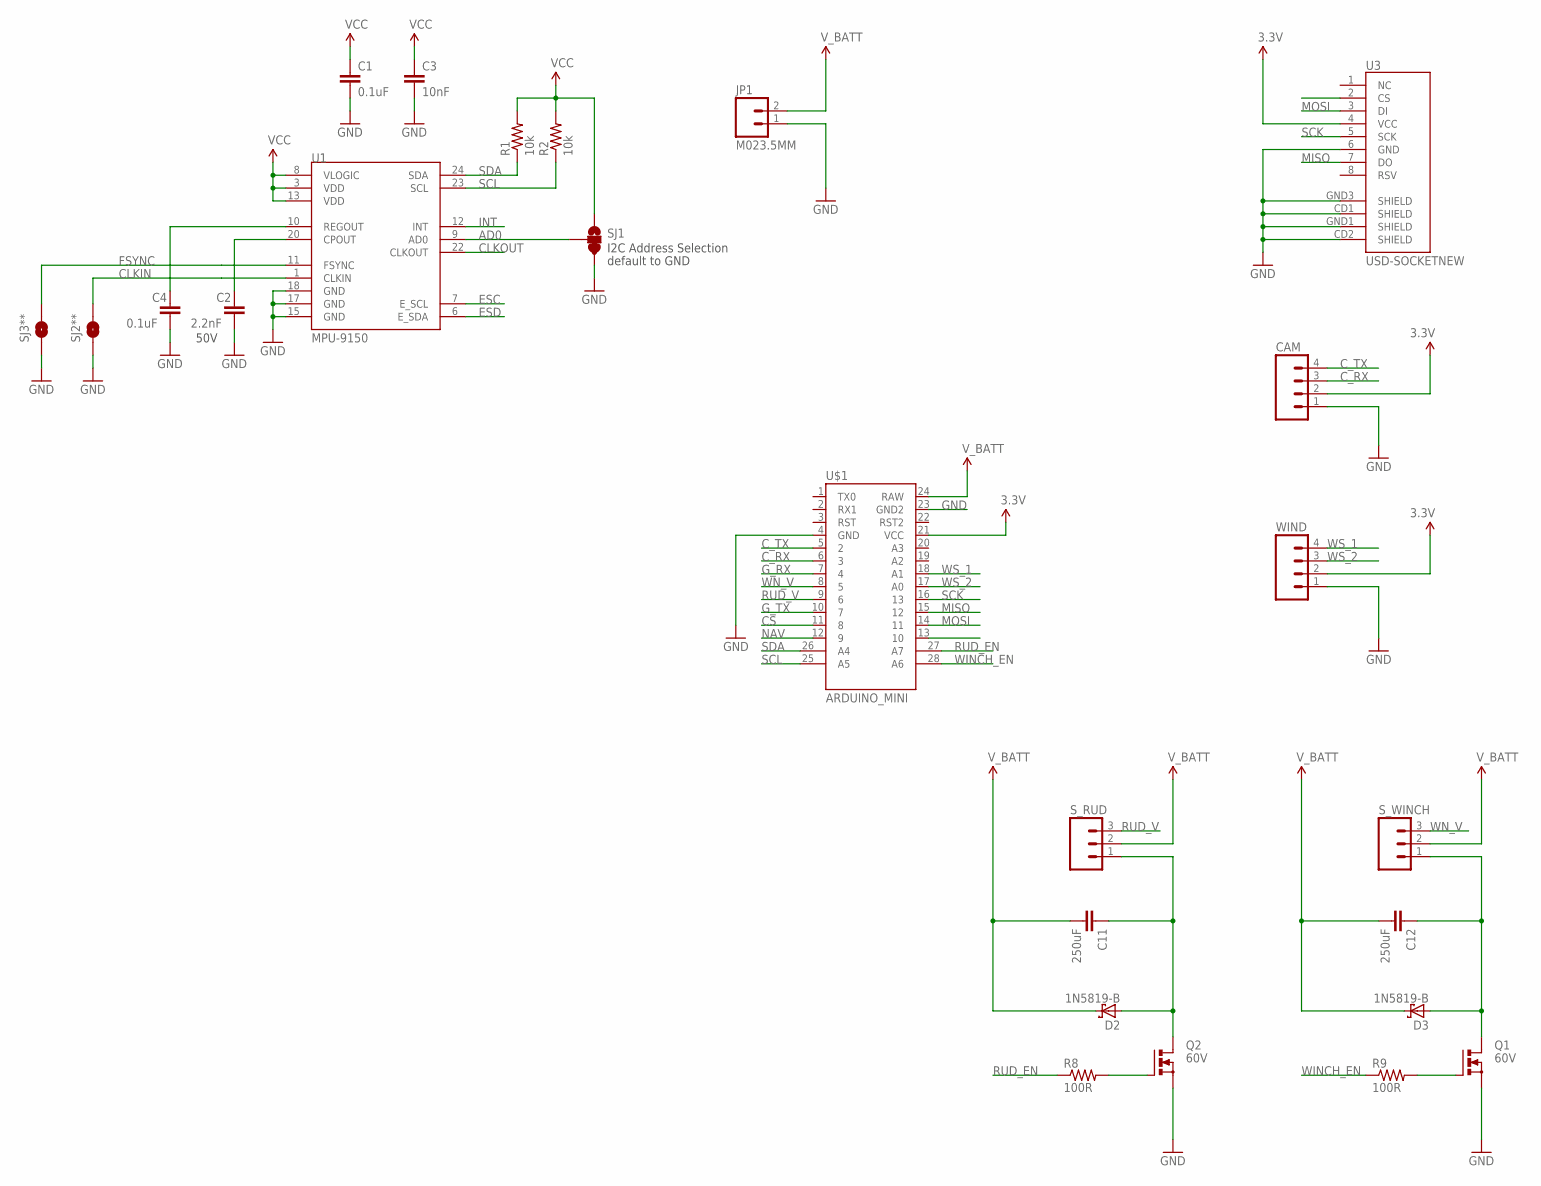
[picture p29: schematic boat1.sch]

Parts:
C1, C4: 0.1uF; 0402-CAP
C2: 2.2nF; 0402-CAP
C3: 10nF; 0402-CAP
C11, C12: 250uF; CAP-PTH-5MM
CAM: M04PTH; 1X04
D2, D3: 1N5819-B; DO41-7.6
JP1: M023.5MM; SCREWTERMINAL-3.5MM-2
Q1, Q2: 60V; TO220BV
R1, R2: 10k; 0402-RES
R8, R9: 100R; 0603-RES
SJ1: SOLDERJUMPER_2WAYPASTE2&3; SJ_3_PASTE2&3
SJ2**, SJ3**: SOLDERJUMPERTRACE; SJ_2S-TRACE
S_RUD: M03PTH; 1X03
S_WINCH: M03PTH; 1X03
U1: MPU-9150; QFN-24-NP
U3: USD-SOCKETNEW; MICRO-SD-SOCKET-PP
U$1: ARDUINO_MINI
WIND: M04PTH; 1X04

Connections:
3.3V: C1.1, C3.1, CAM.2, R1.2, R2.2, SJ1.1, U1.3 (VDD), U1.8 (VLOGIC), U1.13 (VDD), U3.4 (VCC), U$1.21 (VCC), WIND.2
AD0: SJ1.2, U1.9 (AD0)
CLKIN: SJ2**.2, U1.1 (CLKIN)
CLKOUT: U1.22 (CLKOUT)
CS: U$1.11 (8)
C_RX: CAM.3, U$1.6 (3)
C_TX: CAM.4, U$1.5 (2)
ESC: U1.7 (E_SCL)
ESD: U1.6 (E_SDA)
FSYNC: SJ3**.2, U1.11 (FSYNC)
GND: C1.2, C2.2, C3.2, C4.2, CAM.1, JP1.1, Q1.S, Q2.S, SJ1.3, SJ2**.1, SJ3**.1, U1.15 (GND), U1.17 (GND), U1.18 (GND), U3.6 (GND), U3.CD1 (SHIELD), U3.CD2 (SHIELD), U3.GND1 (SHIELD), U3.GND3 (SHIELD), U$1.4 (GND), U$1.23 (GND2), WIND.1
G_RX: U$1.7 (4)
G_TX: U$1.10 (7)
INT: U1.12 (INT)
MISO: U3.7 (DO), U$1.15 (12)
MOSI: U3.3 (DI), U$1.14 (11)
unnamed: C2.1, U1.20 (CPOUT)
unnamed: C4.1, U1.10 (REGOUT)
unnamed: Q2.G, R8.2
unnamed: C12.1, D3.A, Q1.D, S_WINCH.1
unnamed: C11.1, D2.A, Q2.D, S_RUD.1
unnamed: Q1.G, R9.2
NAV: U$1.12 (9)
RUD_EN: R8.1, U$1.27 (A7)
RUD_V: S_RUD.3, U$1.9 (6)
SCK: U3.5 (SCK), U$1.16 (13)
SCL: R2.1, U1.23 (SCL), U$1.25 (A5)
SDA: R1.1, U1.24 (SDA), U$1.26 (A4)
V_BATT: C11.2, C12.2, D2.C, D3.C, JP1.2, S_RUD.2, S_WINCH.2, U$1.24 (RAW)
WINCH_EN: R9.1, U$1.28 (A6)
WN_V: S_WINCH.3, U$1.8 (5)
WS_1: U$1.18 (A1), WIND.4
WS_2: U$1.17 (A0), WIND.3

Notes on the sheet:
50V
I2C Address Selection
default to GND

Board: 2 copper layers, 25 parts (0 on the bottom side), 25 nets, no tracks yet.

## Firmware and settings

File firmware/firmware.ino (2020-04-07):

#define PILOT_DEBUG

#include "logger.h"
#include <Servo.h>
#include "servo_ctl.h"

//#include "LowPower.h"
#include "ahrs.h"

#ifndef NO_SD
#include <SD.h>
#include <Fat16.h>
#include <Fat16util.h> // use functions to print strings from flash memory
#endif

#include "Wire.h"
#include "I2Cdev.h"

#include "MPU6050.h"

#include "trig_fix.h"

#define GPS_BAUDRATE 9600
#define STATUS_LED 32

#define SCAN_RATE_NORMAL 30000
#define SCAN_RATE_FAST 500

#define GPS_WARNING 15000
#define HIGH_RES_GPS_DEFAULT true

#define WAIT_FOR_COMMAND_EVERY 10
#define WAIT_FOR_COMMAND_FOR 1000

#define DATA_FREQ 1500

#define SERIAL_LOGGING_DEFAULT false

#define RC_DATA_FREQ 500

// #define SHOW_MENU_ON_START

#define RAD(v) ((v) * PI / 180.0)
#define DEG(v) ((v) * 180.0 / PI)

// lets you do a logln of a float like so -> logln("blah %d.%d", FP(d))
#define FP(f) (int16_t)f, fracPart(f)
#define FP32(f) (int32_t)f, fracPart(f)

void getCurrentPIDTunings(double* tuningsOut);
void updateCurrentPIDTunings(double* tunings);

void doMenu();

// glancing ahead at the util sketch. todo: make that a c file
int fracPart(float f, int precision = 2);

// Public (extern) variables, readable from other modules

// last time we got a gps update
uint32_t last_gps_time = 0;

// self-explanatory
float gps_lat = 0;
float gps_lon = 0;
char gps_aprs_lat[9];
char gps_aprs_lon[10];
float gps_course = 0;
float gps_speed = 0;
float gps_altitude = 0;
float ahrs_heading = 0;

// winch adjustment to spill extra air if we're heeling too much
float heel_adjust = 0;

// rudder adjustment to compensate for excessive heel. todo: clarify naming; declared in servo_ctl.h
// float heel_offset = 0;

// wind direction
uint16_t wind = 0;
float trailing_wind = 0;

// current loop() count
uint32_t cycle = 0;

// whether the pilot made any changes
boolean adjustment_made = false;

// whether we need high-res gps (drives refresh frequency)
boolean high_res_gps = HIGH_RES_GPS_DEFAULT;

uint32_t last_data_update = 0;
float voltage = 0;

// here so we can log easier
double wp_heading = 0;
float wp_distance = 0;

// what the PID will steer to
double requested_heading = 0;

// mode variables
boolean manual_override = false;

// whether calls to logln should also log to Serial
boolean serial_logging = SERIAL_LOGGING_DEFAULT;
boolean remote_control = false;

// are we tuning the PID
boolean tuningPID = false;

#define AHRS_TRAIL 10
#define WIND_TRAIL 10

#define MPU_PARAM_ADDRESS 0
#define PILOT_PARAM_ADDRESS 256

#ifdef PILOT_DEBUG
float current_pitch;
float current_roll;
float mag_offset;

long sample = 0;
long _heading = 0;

float readSteadyHeading() { 
  float delta_t = (millis() - sample) / 1000.0;
  float turn_speed = map(current_rudder, RUDDER_MIN, RUDDER_MAX, -12, 12);
  
  _heading = toCircleDeg(_heading + turn_speed * delta_t + random(-5, 5));
  
  sample = millis();

  delay(10);
  return RAD(_heading);
}

int mpuInit(int16_t settingsAddress) { return 0; }
void calibrateMag(bool waitForSetup) {}

void windInit() {}
float readSteadyWind() { return 0; }
#endif

AngleCmp ahrs_trail[AHRS_TRAIL];
AngleCmp wind_trail[WIND_TRAIL];

void setup()
{
	pinMode(STATUS_LED, OUTPUT);
	digitalWrite(STATUS_LED, HIGH);

	Wire.begin();

	Serial.begin(9600);
	logInit();

	logln(F("ArduSailor Starting..."));
	Serial2.begin(GPS_BAUDRATE);

	// config value
	mag_offset = 0;// RAD(-15.0);

	logln(F("Initializing servos..."));
	servoInit();
	logln(F("Initializing wind sensor..."));
	windInit();
	logln(F("Initializing MPU..."));
	mpuInit(MPU_PARAM_ADDRESS);
	logln(F("Enabling GPS..."));
	gpsInit();
	logln(F("Starting battery monitor..."));
	batteryInit();
	logln(F("Allocating log trail..."));
	initTrail();

	logln(F("Starting pilot..."));
	pilotInit(PILOT_PARAM_ADDRESS);

	blink(STATUS_LED, 100, 10, HIGH);
	logln(F("Enabling GPS..."));

	warnGPS();

	logln(F("Done. System ready."));

	digitalWrite(STATUS_LED, LOW);

#ifdef SHOW_MENU_ON_START
	doMenu();
#endif
}

void initTrail() {
	ahrs_heading = readSteadyHeading() * 180.0 / PI;
	wind = readSteadyWind() * 180.0 / PI;

	for (int i=0; i<AHRS_TRAIL; i++) {
		ahrs_trail[i].s = sin(ahrs_heading);
		ahrs_trail[i].c = cos(ahrs_heading);
	}

	for (int i=0; i<WIND_TRAIL; i++) {
		wind_trail[i].s = sin(wind);
		wind_trail[i].c = cos(wind);
	}
}

void newTrailingHeadingValue(float new_val, int count, float *target_val, AngleCmp *trail) {
	trail[cycle % count].s = sin(new_val);
	trail[cycle % count].c = cos(new_val);

	float x = 0;
	float y = 0;

	for (int i=0; i<count; i++) {
		x += trail[i].c;
		y += trail[i].s;
	}

	(*target_val) = DEG(toCircle(atan2(y, x)));
}

void newTrailingValue(float new_val, int count, float *target_val, float *trail) {
	trail[cycle % count] = new_val;

	float v = 0;
	for (int i=0; i<count; i++)
		v += trail[i];

	(*target_val) = v / (float)count;
}

void updateSensors(boolean skip_gps) {
	// most of this will be used in human comparison stuff, no need to keep in radians.
	newTrailingHeadingValue(readSteadyHeading(), AHRS_TRAIL, &ahrs_heading, ahrs_trail);
	newTrailingHeadingValue(readSteadyWind(), WIND_TRAIL, &trailing_wind, wind_trail);

	wind = round(trailing_wind);

#ifdef SLEEP_GPS
	if (!skip_gps && (high_res_gps || (last_gps_time == 0) || ((millis() - last_gps_time) > GPS_REFRESH))) {
		updateGPS();

		last_gps_time = millis();
		gps_updated = true;
	} else
		gps_updated = false;
#endif

	if (!high_res_gps && (millis() - last_gps_time > GPS_WARNING))
		warnGPS();

	uint16_t gps_elapsed = millis() - last_gps_time;
	voltage = measureVoltage();
	logln(F("Position: %s, %s (%dms old), Speed: %d.%d, Direction: %d.%d, Wind: %d, Battery %d.%d"),
	gps_aprs_lat,
	gps_aprs_lon,
	gps_elapsed,
	FP(gps_speed),
	FP(gps_course),
	wind,
	FP(voltage));
}

void getMagOffset() {
	bool current_sl = serial_logging;
	serial_logging = true;

	logln(F("Current mag offset is %d.%d"), FP(DEG(mag_offset)));

	Serial.print(F("New offset: "));

	if (!waitForData(5000))
		return;

	float mag_offset_d = Serial.parseFloat();
	Serial.println(mag_offset_d, 4);
	mag_offset = RAD(mag_offset_d);

	Serial.println("Stored.");

	serial_logging = current_sl;
}

void printDataLine() {
	Serial.print(gps_aprs_lat); Serial.print(", ");
	Serial.print(gps_aprs_lon); Serial.print(", ");
	Serial.print(gps_lat, 6); Serial.print(", ");
	Serial.print(gps_lon, 6); Serial.print(", ");
	Serial.print(millis() - last_gps_time); Serial.print(", ");
	Serial.print(gps_speed); Serial.print(", ");
	Serial.print(gps_course); Serial.print(", ");

	Serial.print(ahrs_heading); Serial.print(", ");
	Serial.print(requested_heading); Serial.print(", ");
	Serial.print(current_roll); Serial.print(", ");
	Serial.print(heel_adjust); Serial.print(", ");
	Serial.print(wind); Serial.print(", ");
	Serial.print(wp_heading); Serial.print(", ");
	Serial.print(wp_distance); Serial.print(", ");
	Serial.print(current_rudder); Serial.print(", ");
	Serial.print(current_winch); Serial.print(", ");
	Serial.print(voltage); Serial.print(", ");
	Serial.print(cycle); Serial.println();
}

void loop()
{
	if (!manual_override) {
		logln(F("[Cycle %d start]"), cycle);
		cycle++;
		updateSensors(false);

		checkInput();
		doPilot();
	} else
		// the actual steering commands are handled by doPilot for now
		doPilot();

	if (!serial_logging && (millis() - last_data_update > (remote_control ? RC_DATA_FREQ : DATA_FREQ))) {
		printDataLine();

		last_data_update = millis();
	}
}

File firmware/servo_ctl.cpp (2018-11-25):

#include "servo_ctl.h"

#include <Servo.h>
#include "logger.h"

#define WINCH_PORT 11
#define RUDDER_PORT 10

#define WINCH_EN 27
#define RUDDER_EN 26

#define SP_EN 25

// degrees per second
#define RUDDER_SPEED 300.0
#define WINCH_SPEED 25.0

int heel_offset = 0;
uint8_t current_rudder = 0;
uint8_t current_winch = 0;

bool motor_running = false;

Servo sv_winch, sv_rudder;

void servoInit() {
	pinMode(SP_EN, OUTPUT);
	digitalWrite(SP_EN, LOW);

	pinMode(WINCH_EN, OUTPUT);
	digitalWrite(WINCH_EN, LOW);

	pinMode(RUDDER_EN, OUTPUT);
	digitalWrite(RUDDER_EN, LOW);

#ifndef NO_SAIL
	sv_winch.attach(WINCH_PORT);
#endif

	sv_rudder.attach(RUDDER_PORT);
}

#ifdef NO_SAIL
void runMotor() {
	if (motor_running)
		return;

	digitalWrite(SP_EN, HIGH);
	delay(10);
	digitalWrite(WINCH_EN, HIGH);
	motor_running = true;
}

void stopMotor() {
	if (!motor_running)
		return;

	digitalWrite(WINCH_EN, LOW);
	digitalWrite(SP_EN, LOW);

	motor_running = false;
}
#endif

void centerWinch() {
	winchTo(WINCH_MAX);
}

void centerRudder() {
	rudderTo(90 + heel_offset);
}

void winchTo(int value) {
#ifdef NO_SAIL
	return;
#endif

	int v = constrain(value, min(WINCH_MIN, WINCH_MAX), max(WINCH_MIN, WINCH_MAX));

	logln(F("Winch to %d, constrained to %d"), value, v);

	if (current_winch == v)
		return;

	digitalWrite(SP_EN, HIGH);
	delay(10);
	digitalWrite(WINCH_EN, HIGH);
	delay(10);
	sv_winch.write(v);
	delay(1000 * (abs((current_winch - v))/WINCH_SPEED) + 150);
	digitalWrite(WINCH_EN, LOW);
	digitalWrite(SP_EN, LOW);

	current_winch = v;
}

void normalizedWinchTo(int value) {
	winchTo(map(value, 0, 90, WINCH_MIN, WINCH_MAX));
}

void normalizedWinchTo(int value, int min, int max) {
	winchTo(map(value, min, max, WINCH_MIN, WINCH_MAX));
}

void rudderFromCenter(int value) {
	rudderTo(90 + value);
}

void rudderTo(int value) {
	logln(F("Rudder to %d"), value);

	int v = constrain(value + heel_offset, RUDDER_MIN, RUDDER_MAX);

	if (current_rudder == v)
		return;

	digitalWrite(SP_EN, HIGH);
	delay(10);
	digitalWrite(RUDDER_EN, HIGH);
	delay(10);
	sv_rudder.write(v);
	delay(1000 * (abs((current_rudder - v))/RUDDER_SPEED) + 150);
	digitalWrite(RUDDER_EN, LOW);

#ifndef NO_SAIL
	digitalWrite(SP_EN, LOW);
#else
	if (!motor_running)
		digitalWrite(SP_EN, LOW);
#endif

	current_rudder = v;
}

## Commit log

2014-05-19 initial load
    [board5.brd, board5.sch, boat1.brd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]
2014-05-19 more cleanup
    [board5.brd, board5.sch, boat1.brd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]
2014-06-05 fixed word size for ahrs/wind, rotated ahrs value to match hw install, inverted wind reading, set wind offset and added gps serial start/end to fix servo issue
    [firmware.ino, util.ino, wind.ino]
2014-07-24 first pass at routing
    [boat5.brd, boat5.sch]
2014-08-14 boat v5
    [boat5.brd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]
2014-09-02 board version 5.1
    [boat5.brd, boat5.sch]
2014-09-12 5.1 version final; 1A 5V reg
    [boat5.brd, boat5.sch]
2014-09-17 5.1 final; submitted for build
    [boat5.brd, boat5.sch]
2014-10-13 boat 5, getting ready for mega2560 firmware
    [ahrs.brd, ahrs.sch, boat5.brd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]
2014-10-14 cleanup, porting to 2560
    [boat5.brd]
2015-01-29 more 3d stuff
    [boat5.brd, bracket.skp, bracket.stl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]
2015-03-06 housing updates
    [boat5.brd, rudder mount.skp, rudder mount.stl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]
2015-04-30 circuit updates, firmware tweaks
    [boat5.brd, boat5.sch]
2015-05-24 new calibration params, other fixes
    [boat5.brd, boat5.sch]
2015-08-01 updated weather vane
    [vane 3 mag holder.stl, vane 3.skp, vane 3.stl]
2015-11-08 pilot tuning
    [boat5.brd]
2016-06-27 Added new servo params + GPG test
2016-09-28 Android controller updates, revised layout (v7)
    [ArduSailor.kicad_pcb, ArduSailor.sch, boat6.brd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]
2016-10-27 Finalized v7 board layout / schematic
    [board 7 bom.xlsx, boat7.brd, boat7.sch]
2016-11-12 gitignore changes and cleanup
    [boat7.sch]
2017-03-03 Added remote control operation (ability to set state by transmitting positions for rudder and winch)
2017-03-29 Moving steering to a PID controller
2017-03-30 Playing with PID
2017-04-02 Cleanup, trailing averages for ahrs and wind, tweaking PID parameters
2017-04-03 PID parameter tweak
2017-06-13 Some sample data and a c processor for understanding the logs.
    [PID tuning.xlsx]
2017-06-25 Fix trailing calc bug
    [firmware.ino, logger.cpp, pilot.ino]
2017-07-09 Got averaging for headings working
    [PID tuning.xlsx]
2018-05-19 new route + additional components
    [boat7.brd, outboard mount.skp, outboard mount.stl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]
2018-05-28 manual motor control
2018-11-25 What appears to be a working mpu9250 compass
    [compass mount.skp, compass mount.stl, compass mount~.skp]
2019-11-13 Catching up
    [outboard mount.skp, outboard mount~.skp]
2020-03-18 Added auto-tune library for PID
    [outboard mount.skp, outboard mount~.skp]
2026-10-08 Steer the PID on an unwrapped heading so it turns the short way
    PID_v1 computes error as setpoint - input with no wraparound, so with the
    heading at 10 and the target at 350 it commanded full starboard rudder and
    turned 340 degrees the long way. Tacks that crossed north became 280-degree
    gybe-arounds, and every crossing of north kicked the derivative term by 360.
    Feed the PID a continuous heading instead: accumulate the shortest turn
    between readings, and put the setpoint the shortest signed distance to
    requested_heading away from it. Derivative-on-measurement behaviour and the
    autotuner (which also watches the input) are otherwise unchanged.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
2026-10-08 Fix starboard-tack sail trim and reverse heel compensation
    wind was a uint16_t, and int is 16 bits on AVR, so in adjustSails()
    wind - 180 was unsigned: any apparent wind from 1-179 degrees (starboard
    side) became ~65000, clamped to 180, and sheeted the sail fully in no
    matter the point of sail. Make wind an int16_t (values are 0-360).
    Heel compensation subtracted heel_adjust, which eased the sheet before
    031beb0 swapped the winch range; since then it has been pulling the sheet
    in as the boat heels. Ease toward WINCH_MIN (the fully eased end of the
    trim map) whichever way the range runs.
    The decay also multiplied by HEEL_COMP_DECAY (0.1), dropping 90% per
    cycle; reduce by 10% per cycle as t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
2026-10-08 Average compass samples as unit vectors
    readSteadyHeading() took the arithmetic mean of headings in [0, 2pi), so
    samples either side of the sensor's zero (e.g. 359 and 1 degrees) averaged
    to ~180. With the sensor mounted backwards that hit when the boat pointed
    roughly magnetic south. Sum sin/cos instead, like the trailing averages in
    firmware.ino already do, and only accumulate samples that were actually read.
    Claude-Session: https://claude.ai/code/session_013apgw9zvbjAaXsPhgVz8SB
2026-10-08 Move build switches into config.h and fix the sailing build
    PILOT_DEBUG was defined separately in firmware.ino and ahrs.cpp, and
    NO_SAIL in pilot.ino and servo_ctl.h, so switching to the sailing build
    meant editing four files and missing one left the translation units
    disagreeing. Define PILOT_DEBUG, NO_SAIL and NO_SD once in config.h and
    include it wherever they are tested. The defaults are unchanged (bench
    test, motor mode, serial logging only).
    With NO_SAIL off the sketch didn't compile: the menu's auto-calibrate
    option called runMotor()/stopMotor(), which only exist in motor mode.
    Only run the motor in motor mode; under sail the boat circles on the
    rudder alone if it's already moving.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
2026-10-22 Fix compass calibration and read the AK8963 at 16-bit, 40Hz
    Calibration (calibrateMag):
    - running_min/max started at 0, so an axis whose hard-iron offset is
    bigger than the horizontal field never moved its min (or max) off 0.
    This board's Y offset (~+34 counts at 14-bit, per the 2017 and 2018
    calibrations in the history) is bigger than Chicago's ~20 counts of
    horizontal field, so a flat calibration put the Y centre at ~26 and
    headings were off by up to ~25 degrees depending on direction. Start
    from INT16_MAX/MIN, and reset calibrationSteps so a second calibration
    in one power cycle actually runs.
    - The Z offset (~-28 counts) was never subtracted, so tilt compensation
    read it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
2026-10-22 Read a fresh, aligned DMP packet every time
    readFIFOPacket() read the oldest packet in the FIFO, so a heading could
    be up to ~200ms old (the rest of the loop lets 10 packets queue). And
    the MPU-9250's FIFO is 512 bytes, not 1024, so the "== 1024" overflow
    check never fired, and 512 isn't a whole number of 48-byte packets:
    when a packet landed between the INT_STATUS check and the read, the
    overflow dropped bytes and the packet was read misaligned (garbage
    quaternion and magnetometer values).
    Reset the FIFO and wait for the next packet the DMP finishes. If the
    reset caught the DMP partway through a packet, the count isn't a
    multiple of the packet size: reset again.
    Against a simulated FIFO w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
2026-10-22 Keep a NaN heading out of the averages and the steering
    A zero magnetometer vector (compass not answering, or no calibration
    stored) makes heading() normalise a zero vector, returning NaN. That NaN
    stayed in the 10-sample heading average and, through the unwrapped
    steering input, in the PID for good.
    readSteadyHeading() now skips NaN samples and keeps the last good
    heading when none are valid, and unwrapHeadings() ignores a NaN heading
    or target, so the steering recovers on the next good reading.
    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
2026-10-22 Correct compass headings for magnetic declination
    The compass reads magnetic north but waypoint bearings are computed from
    lat/lon (true north), and mag_offset was 0, so every heading was off by
    the local declination: 4.2 degrees west at the waypoints (WMM2025).
    Add MAG_DECLINATION to config.h and apply it at startup. The menu's mag
    offset option still overrides it until the next restart.
    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
2026-10-28 Add a simulator that runs the firmware against a simulated boat
    sim/build.py compiles the unmodified firmware natively (joining the .ino
    files like the Arduino IDE, with a stand-in Arduino core underneath) and
    links it with a simulated world: a ~1m single-sail yacht with sail,
    keel and rudder forces, heel and weather helm, waves, and gusty,
    shifting wind. The MPU-9250 (DMP FIFO and the AK8963 behind its I2C
    master), wind vane, GPS, battery divider and servos are modelled at the
    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
2026-10-28 Simulator: fix the rudder going backwards and stalled; show late pages current settings
    The rudder's angle of attack took the stern's sideways flow with the wrong
    sign when the boat was going backwards, and a stalled rudder had less drag
    than an unstalled one. Both matter for getting out of irons. A stalled
    rudder now brakes like a flat plate.
    A browser that connected after a setting or waypoint changed showed the
    values from when the simulator started. run.py now replays the latest
    change to each.
    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
2026-10-28 Beat upwind in a corridor, tack only with way on, and recover from irons
    The pilot used to flip tacks every 30 seconds whatever the boat was doing,
    with no handling for stopping head to wind. Now:
    - Upwind (the waypoint within IRONS of the wind) it sails close-hauled and
    zigzags up a corridor CORRIDOR metres either side of the line from where
    the leg started, tacking at the edges, until it can lay the waypoint on
    one tack (with LAYLINE_MARGIN for the apparent wind swinging aft).
    - The requested heading is never in the no-go zone, and it only crosses
    the wind (tacks) with MIN_TACK_SPEED on and MIN_TACK_INTERVAL after the
    last tack. Too slow, it bears away FOOT_ANGLE to build speed;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
2026-10-29 Tack from the edge of the no-go zone, and steer for the waypoint whenever it's fetchable
    In strong wind and big waves the pilot often didn't steer for a waypoint the
    wind allowed, and tacked from well off the wind, failing several times
    before it gybed. Two parts of the last change caused that:
    - After a tack or getting out of irons, a gradual luff limit held the boat
    up to 90 degrees off the wind for several seconds, even when the waypoint
    was fetchable. With waves knocking the boat from side to side it was
    almost always active.
    - Before a tack it bore away 15 degrees to build speed, and after irons it
    could start the next tack from wherever the luff limit had got to, often
    near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

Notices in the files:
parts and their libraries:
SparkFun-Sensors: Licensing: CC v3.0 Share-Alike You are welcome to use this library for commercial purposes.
